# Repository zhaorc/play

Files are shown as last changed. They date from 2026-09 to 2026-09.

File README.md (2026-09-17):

# 纸带钢琴工坊

将 MIDI 乐曲转换为机械纸带钢琴的打孔数据，提供从编曲、试听到上机打孔的一体化工具链。

目标机器是一台机械纸带钢琴：双排键盘（上排和弦、下排主旋律）每档 8 个白键（简化键盘槽位 15 格、每排 17 条滚轮轨），纸带自下而上走带，孔位经过滚轮触发拨片发声。换挡键孔（◀◀/▶▶）可移动键盘音域窗口（每按一次 ±1 档 = 一个八度），8 个档位 A0→A1→A2→A3→A4→A5→A6→C7 合起来覆盖钢琴全音域 A0..C8。

## 仓库结构

```
play/
├── perfect-piano/            纸带打孔工作室（网页应用，零依赖）
│   ├── index.html            主程序入口（双击即用）
│   ├── test.html             自测页（137 项断言）
│   ├── js/
│   │   ├── pp-tape.js        纸带数据模型与 MIDI 转换管线（核心）
│   │   ├── app.js            主程序：渲染 / 编辑 / 播放 / 导出
│   │   ├── midi-parser.js    MIDI 文件解析
│   │   ├── synth.js          Web Audio 发声模拟
│   │   └── punch-sender.js    打孔机上位机（Web Serial）
│   ├── test/                 换挡逻辑测试曲（MIDI）
│   └── tools/                测试曲生成脚本
├── puncher/
│   └── firmware/puncher/     Arduino Nano 打孔机固件（puncher.ino）
├── midi/                     示例曲（梦中的婚礼、土耳其进行曲）
├── 打孔机.md                 打孔机硬件规格
└── 打孔机-设计方案.md         打孔机设计文档（架构 / 标定 / 协议）
```

## 快速开始

1. **打开工作室**：双击 `perfect-piano/index.html`（推荐 Chrome / Edge，零安装零依赖）。
2. **导入乐曲**：点击「导入 MIDI」选择 `.mid` 文件，或使用「示例曲」直接体验。
   - 多轨文件默认按音域均值自动分配：最高轨 → 主旋律（下排），其余轨 → 和弦（上排）。
   - 单轨文件默认开启「按音高拆分」，低于 C4 的音自动归入和弦排。
3. **预览试听**：播放模拟真实纸带机行为（含换挡时序、双排 105mm 站间错位）。
4. **导出图纸**：导出 1:1 SVG / PNG 用于参考，或保存工程 JSON 后续编辑。

## MIDI 转换管线

- 音高按原音精确落轨（不做移调）：白键/黑键各占自己的槽位，虚拟黑键位（B-C、E-F 处）占位不发声
- 超出当前档位窗口时自动调度换挡键孔：基于真实时间提前量（400ms 换挡 + 200ms 余量）
- 密集音符物理无法打孔时（同轨孔心距 < 4.0mm）自动整曲拉长每拍毫米数，节奏零失真
- 同拍双排孔在带长方向相距 105mm（两排滚轮的物理站间距）

## 打孔机

网页端「打孔机」面板通过 Web Serial（115200）控制 Arduino Nano 固件，完成自动打孔：

- **固件**：`puncher/firmware/puncher/puncher.ino`（Arduino Nano + 2×THB6128 + PWM 舵机）
  - X 轴：Φ24mm 滚轮走带（339.53 脉冲/mm）；Y 轴：1模21齿齿轮齿条（388.03 脉冲/mm）
  - 梯形加减速脉冲引擎、打孔状态机（下压 45° → 钻孔 2s → 抬起 90°）
  - ASCII 行协议：`V/O/J/P/Z0/Z1/F/C/Q/R`；EEPROM 保存标定当量；急停与预留限位
- **上位机**：工作室内打孔面板——点动对刀、设原点、当量校准、逐孔 ACK 流控、暂停/急停、`.punch` 任务文件导出

使用流程：连接 → 点动对刀 → 设为原点 → 生成任务 → 开始打孔。

详细设计见 [打孔机-设计方案.md](打孔机-设计方案.md)。

## 自测

浏览器打开 `perfect-piano/test.html`，覆盖槽位模型、档位表、轨位几何、换挡调度、最密间隔拉长、端到端转换、打孔任务生成等 174 项断言。

## 硬件规格摘要

| 项 | 值 |
|---|---|
| 纸带宽 | 150mm |
| 档位宽 | 130mm（N=8 白键，白:黑 = 7:6） |
| 每排轨数 | 17（◀◀ + 15 槽位 + ▶▶），槽栅距 8.622mm，上下排错开 D=4.311mm |
| 每拍走带 | 9mm（默认，密集曲自动拉长） |
| 两排站间距 | 105mm（沿走带方向） |
| 换挡 | 整档键 ±1 挡（= 一个八度），耗时 400ms，提前量 600ms，曲首连按 3 次 ◀◀ 钉底 A0 |
| 最小孔距 | 4.0mm（任意两孔孔心距 ⟺ 孔缘间距 1.5mm） |

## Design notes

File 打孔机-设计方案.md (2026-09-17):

# 打孔机程序设计方案

> 依据：`打孔机.md` 硬件规格（2026-09-14）
> 状态：**已确认，固件 v1.0 已完成**（Nano 编译通过：Flash 29% / RAM 17%；确认结论见第六节）

## 一、系统总体架构

```
┌─────────────────────────┐   USB 串口(有线)   ┌──────────────────────┐
│  PC 端（上位机）          │  文本行协议 115200  │  Arduino Nano 固件     │
│  perfect-piano 网页扩展  │ ◄──────────────► │  ATMEGA328P (2KB RAM) │
│  · 孔位→机器坐标换算      │   P / J / O / R   │  · X/Y 步进脉冲发生    │
│  · 手动对刀/校准/试打      │                   │  · Z 伺服打孔循环      │
│  · 任务流式下发+进度回读   │                   │  · 逐孔 ACK 流控       │
└─────────────────────────┘                   └──────────────────────┘
                                                      │
                              X: THB6128→17HS2408s（滚轮走带）
                              Y: THB6128→17HS2408s（齿轮齿条横移）
                              Z: 舵机/伺服 45°下 / 90°抬
```

数据流复用现有成果：`state.holes`（col,row,lane）→ `PP.holeYMM()` 和 `PP.laneXMM()` → 毫米坐标 → 串口逐孔下发，固件负责脉冲与打孔时序。

## 二、机械标定（关键常量）

128 细分下每圈脉冲 = 200 × 128 = **25600 脉冲/圈**

| 轴 | 传动 | 每圈走距 | 理论脉冲/mm |
|---|---|---|---|
| X（走带长度方向） | Φ24mm 滚轮直连摩擦 | π×24 = 75.40mm | **339.53** |
| Y（纸带宽度方向） | 1模21齿齿轮齿条，节圆 Φ21mm | π×21 = 65.97mm | **388.03** |
| Z | 伺服 | 90°抬 / 45°下，下压保持 **2s** | — |

- 理论值仅作初值，固件支持标定命令微调（补偿滚轮打滑/齿轮公差），存入 EEPROM
- 坐标映射：**机器 X = 纸带长度（holeYMM），机器 Y = 纸带宽度（laneXMM，约 3.44~146.56mm）**
- 行程上限：Y 需覆盖 150mm 带宽（≈5820 脉冲）；X 一首歌可达数米，脉冲数用 int32（上限约 6km，安全）
- 孔按 **机器 x（纸带长度）升序为主、y（宽度）升序为辅** 排列打孔顺序——纸带单向进给不可倒带，同 x 位置的孔先打低 y 再打高 y

## 三、固件设计（`puncher/firmware/puncher/puncher.ino`，已实现并编译通过）

**引脚分配**

| 信号 | 引脚 | 说明 |
|---|---|---|
| X: PUL/DIR/ENA | D2/D3/D4 | THB6128 光耦输入，ENA 低有效 |
| Y: PUL/DIR/ENA | D5/D6/D7 | THB6128 光耦输入，ENA 低有效 |
| X 原点限位（预留） | D8 | INPUT_PULLUP，未装时空置；移动中触发即急停 |
| Z 舵机 | D9 | PWM 50Hz，Servo 库（ATmega328P 硬件 PWM 引脚） |
| 硬件急停按钮（预留） | A0 | INPUT_PULLUP，未接空置；轮询触发等同 `R` 命令 |
| Y 原点限位（预留） | A1 | INPUT_PULLUP，未装时空置 |

**实现要点**

- 脉冲用 `digitalWrite` + `micros()` 定时（10mm/s 进给 ≈ 3.4~3.9kHz，Nano 无压力）；非阻塞状态机，每步按加减速斜坡实时算脉冲间隔，保证 `R` 急停随时可响应
- 单孔动作序列：X 进给到位 → Y 横移到位 → Z 舵机转到 45° → 保持 2.0s → Z 回到 90° → 回 `DONE`
- RAM 只保留单行命令缓冲（2KB 内存限制），靠上位机 ACK 流控（收到 DONE 再发下一孔），不做整块缓存；执行中收到除 `R` 外命令回 `ERR BUSY`
- 上电默认 Z=90°（抬起）、使能步进、等待原点设定；EEPROM 存 magic+脉冲当量，首次烧录自动写默认值
- Z 轴确认为标准 PWM 舵机（3 线，50Hz，脉宽 0.5~2.5ms 对应 0~180°），由 D9 硬件 PWM 输出；舵机须独立供电（5V BEC），勿取 Nano USB 电源

**串口协议**（ASCII 行，`\n` 结尾，应答 `OK/DONE/ERR`）

| 命令 | 含义 |
|---|---|
| `V` | 版本握手，回 `PUNCHER v1.0 READY` |
| `O` | 当前位置设为原点（手动对刀后） |
| `J <x> <y>` | 点动到绝对毫米位置（不打孔），到位回 DONE |
| `P <x> <y>` | 在绝对坐标打一个孔（走完+2s循环，回 DONE） |
| `Z0 / Z1` | 手动抬钻 90° / 压钻 45°（调试用） |
| `F <mm/s>` | 设置进给速度（默认 10，范围 1~50） |
| `C <xpmm> <ypmm>` | 校准脉冲当量，写 EEPROM 永久保存 |
| `Q` | 查询当前位置，回 `POS <xmm> <ymm>` |
| `R` | 急停：立即停脉冲、抬钻，回 `OK ESTOP` |

## 四、PC 端设计（扩展现有网页）

新增 `js/punch-sender.js` + 界面"打孔"面板：

1. **任务生成**：从当前 `state.holes` 直接换算毫米坐标（含换挡键孔，lane 0/16 在档位宽度外 shiftGap=4.4mm 处），按走带方向排序；可导出 `.punch` 文本任务文件（每行 `P x y`）离线备用
2. **连接与控制**：Web Serial API（Chrome/Edge），连接/断开、115200、版本握手
3. **对刀流程**：手动点动 X/Y → 钻头对准纸带头部第一孔位参考点 → `O` 设原点
4. **执行面板**：试打单孔（不装钻头干跑 Z）→ 试打前 N 孔 → 整曲发送；实时进度（第 k/总孔数、当前坐标），暂停/继续/急停
5. **校准面板**：输入实测走距反推脉冲当量，下发 `C`
6. 安全细节：发送前显示"X 总行程 xx 米 / 共 xx 孔 / 预计 xx 分钟"（每孔 2s+进给时间）需确认；Z 抬起状态失能"开始"

## 五、实施步骤

1. ✅ `puncher/firmware/puncher/puncher.ino` 固件 + 协议解析/脉冲引擎/打孔状态机（2026-09-14 完成，arduino-cli 编译通过）
2. ✅ `test.html` 协议层纯逻辑断言：任务排序（x 主序 y 次序）、坐标映射、拉长曲换算、P 命令格式、用时估算、.punch 导出（2026-09-14 完成，含 14 项"打孔："断言）
3. ✅ 网页端打孔面板 + Web Serial + 任务生成/导出（`js/punch-sender.js`，2026-09-14 完成：连接/握手/对刀/点动/进给/校准/试打/逐孔 ACK 流控/暂停/急停/.punch 导出）
4. 无硬件自测：固件协议用 PC 端串口模拟器对跑（干跑模式，禁 Z）
5. 上机调试：对刀→单孔→多孔→整曲

## 六、确认结论（2026-09-14）

1. **轴向对应**：✅ 机器 X（滚轮走带）= 纸带**长度方向**；机器 Y（齿轮齿条）= 纸带**宽度方向**。固件映射：机器 (x, y) = (holeYMM, laneXMM)
2. **原点方案**：✅ 默认"手动对刀 + `O` 软件设原点"；固件同时预留 X(D8)/Y(A1) 限位引脚与 A0 硬件急停，未安装时空置不影响使用，后期装开关即可扩展自动回零
3. **上位机形态**：✅ 集成进现有 perfect-piano 网页，Web Serial API（Chrome/Edge 桌面；Android Chrome + OTG 亦可），实际使用走 localhost 或 https 安全上下文
4. **Z 轴接口**：✅ 确认为 **PWM 舵机**（50Hz，45° 下压 / 90° 抬起，下压保持 2s），接 D9 硬件 PWM，Servo 库驱动，独立 5V 供电

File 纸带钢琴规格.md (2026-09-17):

* 1、纸带钢琴.png是手机上的钢琴app的截图，键盘模式，双排键盘，标准键盘（既有白健也有黑键），每个档位是N个白键，N是可调节参数。
* 2、初始档位是A0档，记住：xx档的意思是最左侧是xx键的档位。
* 3、最低档是A0，最高档是C7档（机械上止点；C7 档窗口 C7..C8，与各低档合起来覆盖钢琴全音域 A0..C8）
* 3.1、N 取值定为 8（唯一自洽解：窗口 2N-1=15 槽 = 13 真实键 + 2 虚拟黑键位，档位步进 14 槽恰为一个八度）
* 4、单箭头按钮未使用，两侧双箭头按钮点击后切换档位，按一次切换一个档位（单换挡，即整档键 ±1 档 = ±12 半音），换档时间约400毫秒，到位前键盘仍按旧档击发
* 5、上排弹奏和旋，下排弹奏主旋律
* 6、每个按键（白健、黑键）、双箭头按钮由一个滚轮带动拨片控制，滚轮由打孔纸带驱动（类似纸带音乐盒）
* 7、共有两排滚轮分别控制两排键盘，控制和旋的称为上排滚轮，控制主旋律的称为下排滚轮
* 8、两排滚轮平行排列、在纸带的运动方向上的间距是105mm，为防止干涉，下排滚轮比上排滚轮向右偏移D毫米，D由计算得出。
* 9、纸带总宽度是150mm。档位宽度（最左键的左侧到最右键的右侧的距离）是130mm。
* 9.1、由档位宽度 130mm 与 N=8（白:黑 = 7:6）定出：白键宽 w=130×7/98≈9.286mm，黑键宽 b=6w/7≈7.959mm，槽栅距（相邻槽位中心距）p=(w+b)/2=13w/14≈8.622mm
* 9.2、D 取半槽栅距 p/2≈4.311mm：两排在统一槽栅上错开半个槽位，跨排任意两孔孔心距最小恰为 D≈4.311mm
* 10、换挡控制滚轮不占用档位宽度，档位宽度全部用来排布键盘控制滚轮。
* 11、标准键盘的黑键是嵌在相邻的两个白健之间，黑键的长度约为白健的一半。将键盘布局简化一下，简化后的键盘，黑键和白健的长度相同，每两个白健之间都有一个黑键（对于实际不存在的黑键，比如EF之间没有黑键也要插入一个虚拟黑键用来占位），白健与黑键宽度比值是7:6
* 12、纸带的打孔直径为2.5mm（孔半径1.25mm），要求孔间距不能小于1.5mm（指孔边缘之间的距离，即任意两孔孔心距不小于 1.5+2.5=4.0mm），最外侧孔缘距纸带边界不小于1.5mm。
* 12.1、换挡滚轮中心距档位边缘 shiftGap=4.4mm（两侧对称）；该布局下最外孔缘距带边约2.19mm，跨排孔心距最小为 D≈4.311mm、换挡孔与对排端键孔约4.732mm，均满足规格，无需事后微移。

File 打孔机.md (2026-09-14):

# 打孔机
* 打孔机的x轴是由步进电机（记作电机x）直连滚轮通过摩擦力带动纸带沿x轴方向行走，滚轮直径24mm
* 打孔机的y轴是由步进电机（记作电机y）通过齿轮带动齿条沿y轴行走，齿轮规格是1模21齿
* 打孔机的z轴是由PWM舵机（记作电机z）带动打孔钻头沿z轴引动，钻头抬起的伺服电机行程角度是90度，钻头放下的电机角度是45度，钻孔时间为2s
* 打孔机的控制板是Arduino Nano（ATMEGA328P）
* 步进电机型号是NEMA 17HS2408s，驱动板是THB6128，采用128细分
* 电脑作为打孔数据输入端，有线连接

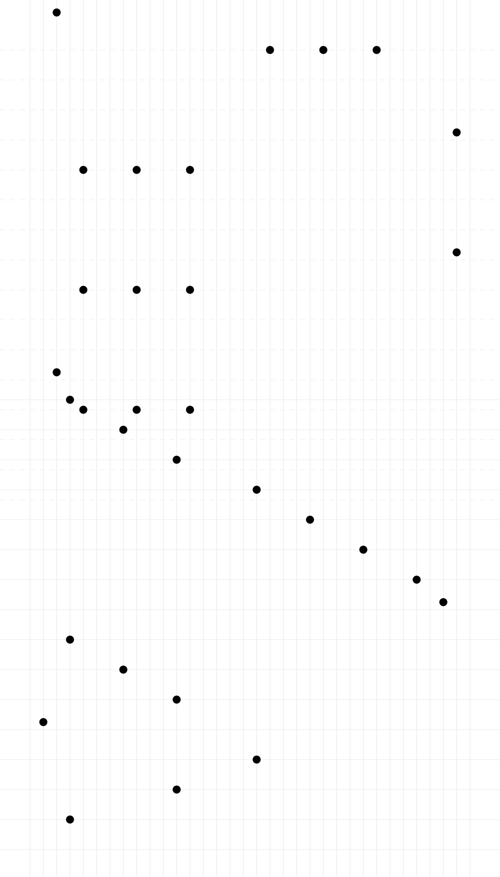
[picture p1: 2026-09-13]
纸带打孔图.png

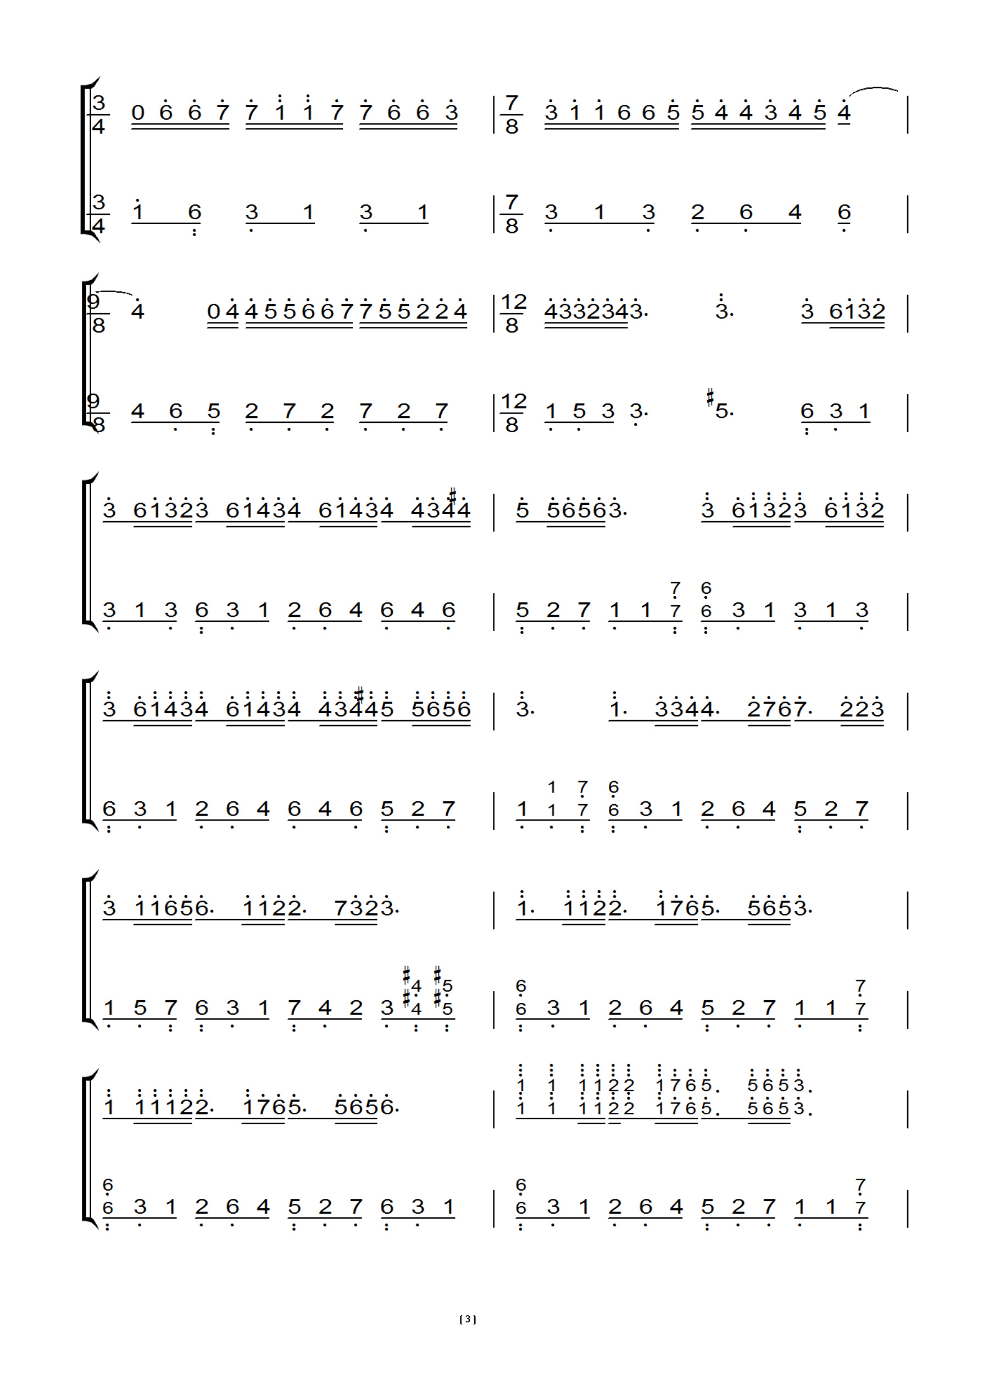
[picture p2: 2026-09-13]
梦中的婚礼.png

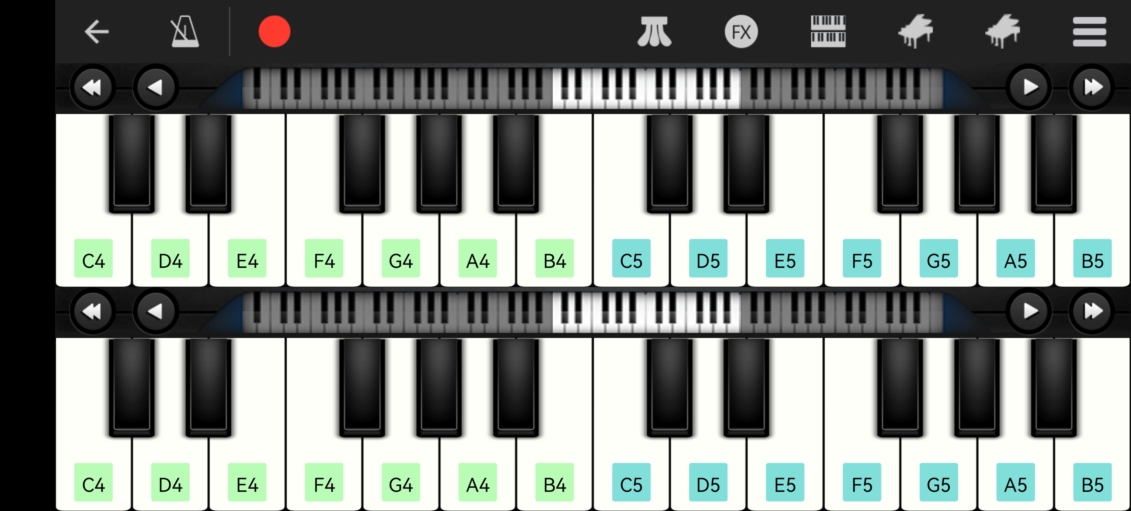
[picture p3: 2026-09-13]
纸带钢琴.jpg

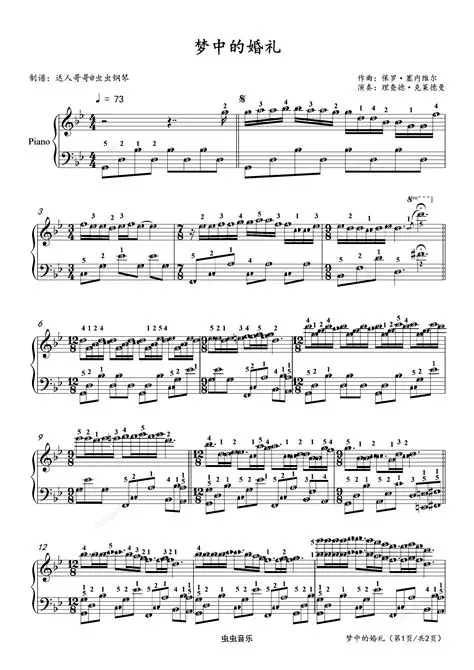
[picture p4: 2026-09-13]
梦中的婚礼.webp

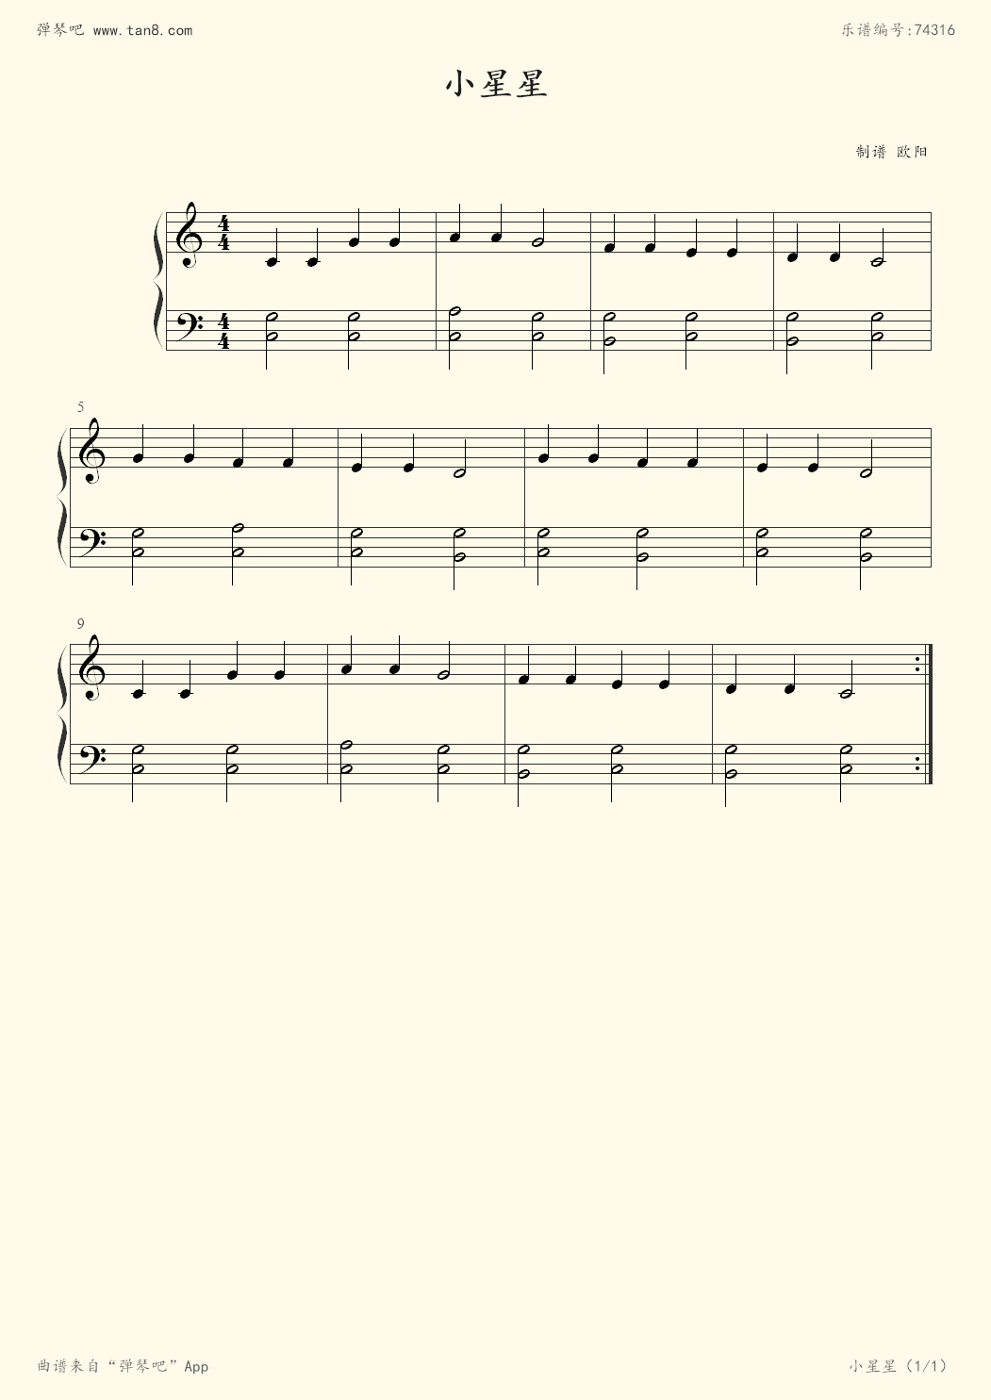
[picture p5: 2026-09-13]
小星星.png

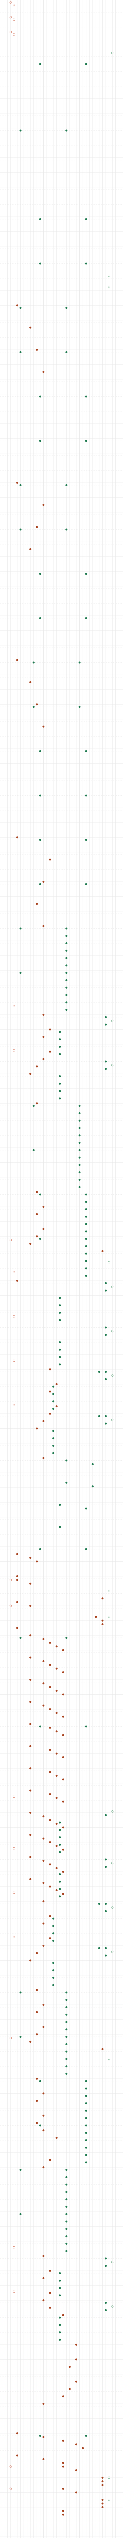
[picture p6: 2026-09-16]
perfect-piano/westworld_theme_纸带.png

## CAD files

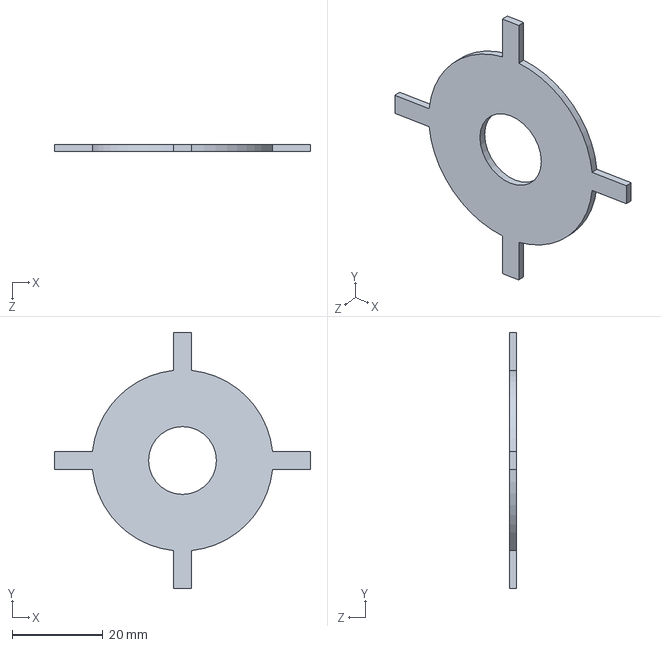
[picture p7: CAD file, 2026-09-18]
cad/roller_d40x1p5_h15.SLDPRT
56.6 x 56.6 x 1.50 mm

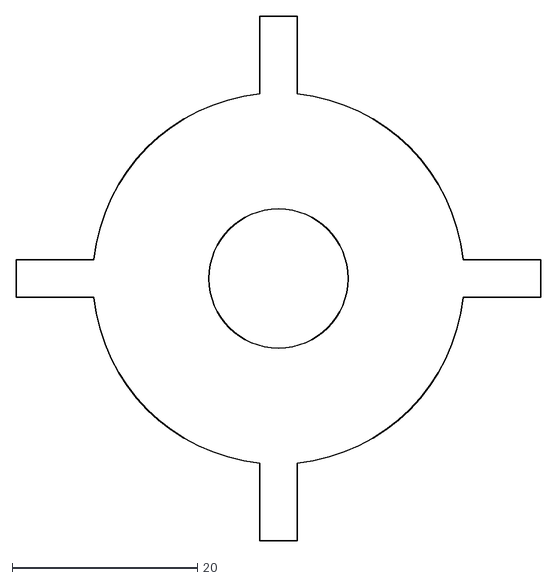
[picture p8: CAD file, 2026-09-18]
cad/roller_laser_pvc1p5.dxf
56.6 x 56.6

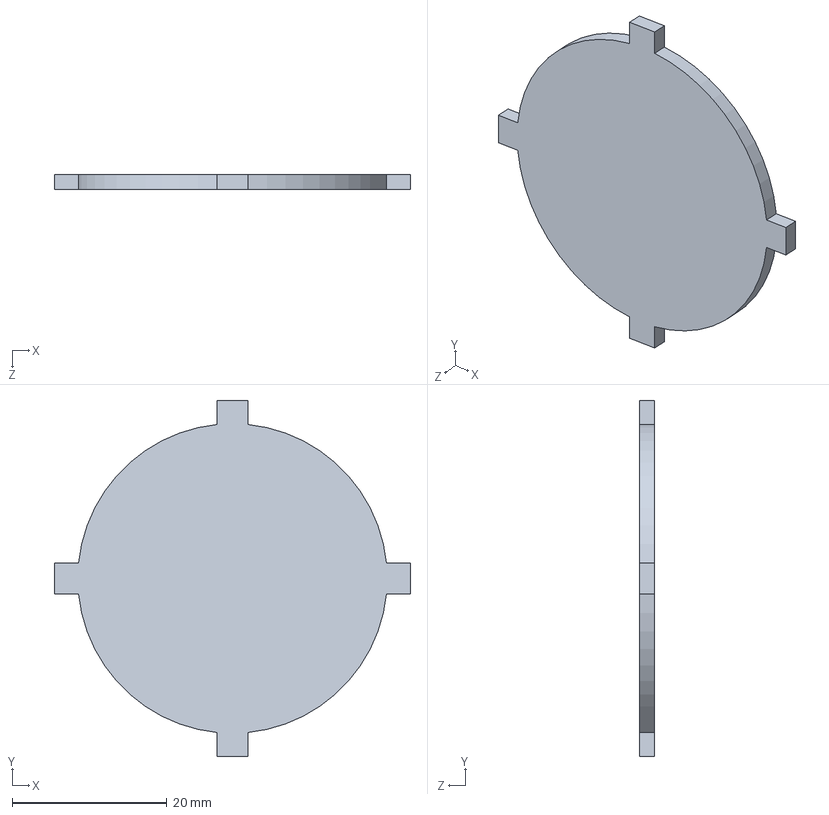
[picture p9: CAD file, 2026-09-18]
cad/roller_d40x2_4bumps.SLDPRT
46.0 x 46.0 x 2.00 mm

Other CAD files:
cad/roller_d40x1p5_h15_views.SLDDRW
cad/roller_d40x2_4bumps_views.SLDDRW

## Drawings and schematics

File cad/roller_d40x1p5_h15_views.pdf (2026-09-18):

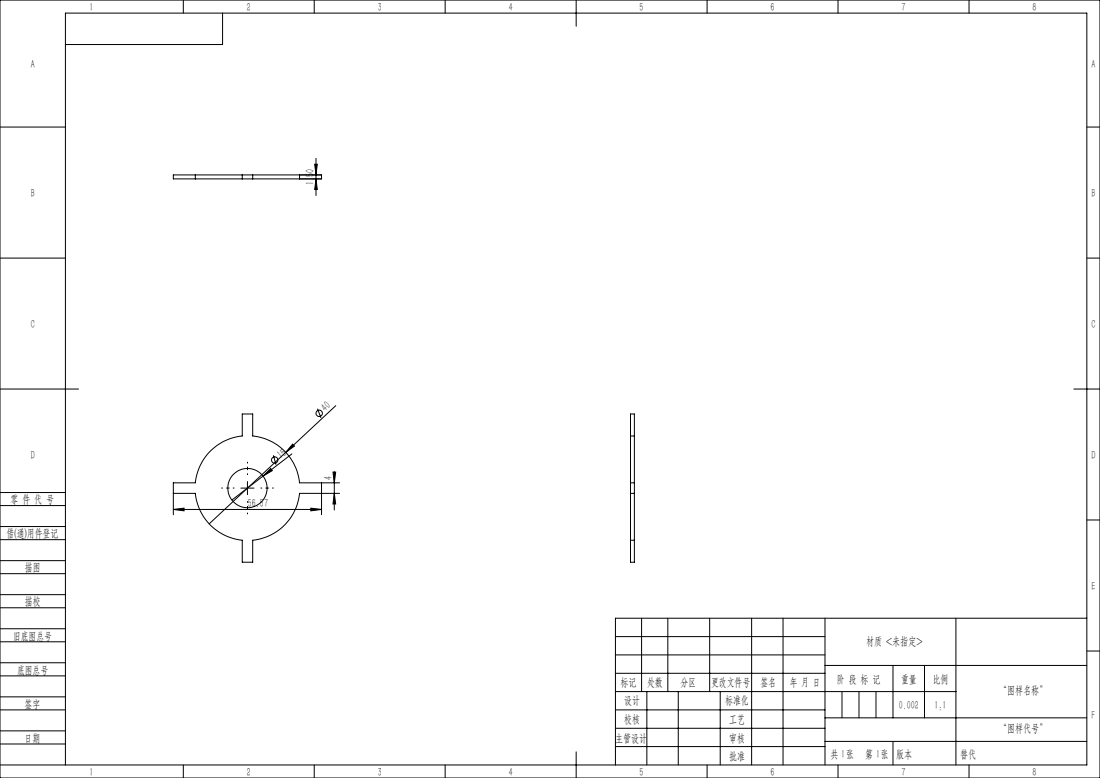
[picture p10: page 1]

材质 <未指定>

阶 段 标 记 | 重量 | 比例 | “图样名称”

标记 | 处数 | 分区 | 更改文件号 | 签名 | 年 月 日
设计 | | | 标准化 | | | | | 0.002 | 1:1
校核 | | | 工艺
主管设计 | | | 审核

“图样代号”

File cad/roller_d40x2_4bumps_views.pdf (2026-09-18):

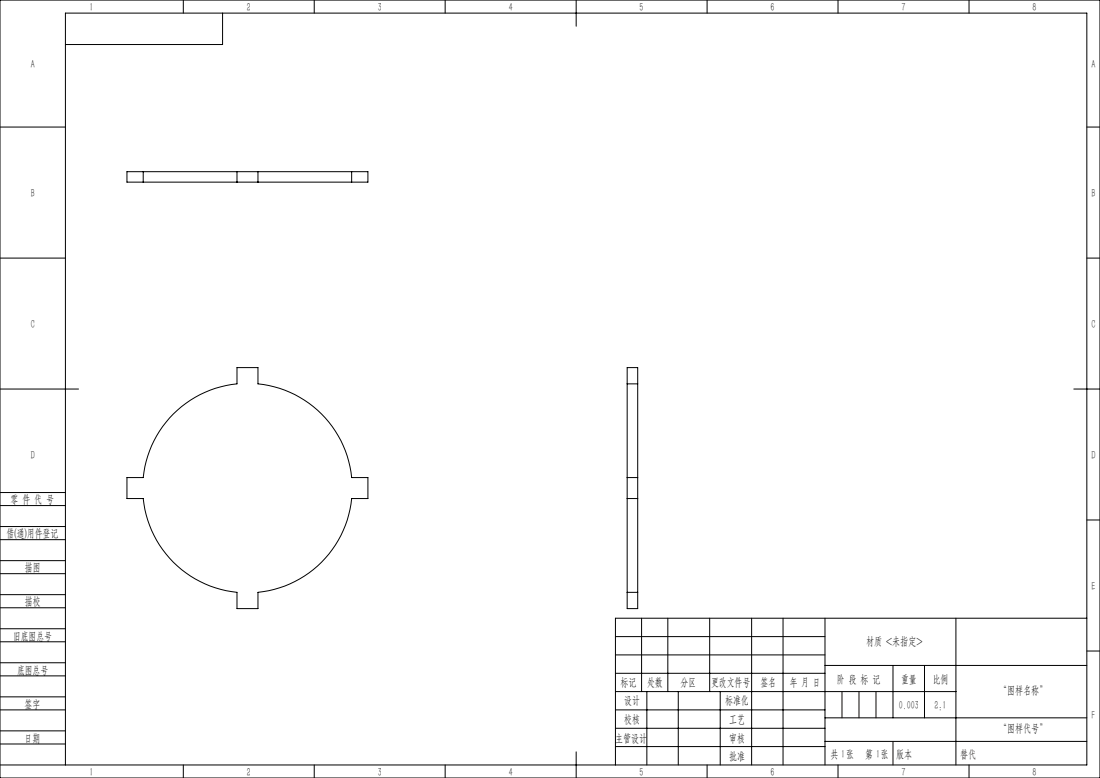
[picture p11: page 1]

材质 <未指定>

阶 段 标 记 | 重量 | 比例 | “图样名称”

标记 | 处数 | 分区 | 更改文件号 | 签名 | 年 月 日
设计 | | | 标准化 | | | | | 0.003 | 2:1
校核 | | | 工艺
主管设计 | | | 审核

“图样代号”

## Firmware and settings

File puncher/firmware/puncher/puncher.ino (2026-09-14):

/* ============================================================
 * 打孔机固件 puncher.ino
 * 纸带钢琴打孔机 · Arduino Nano (ATmega328P)
 *
 * 硬件（依据 打孔机.md / 打孔机-设计方案.md）：
 *   X 轴：NEMA 17HS2408 + THB6128（128 细分），直连 Φ24mm 滚轮摩擦走带
 *         25600 脉冲/圈 → π×24 = 75.40mm/圈 → 339.53 脉冲/mm
 *   Y 轴：同款电机驱动，1模21齿齿轮 + 齿条，节圆 Φ21mm
 *         25600 脉冲/圈 → π×21 = 65.97mm/圈 → 388.03 脉冲/mm
 *   Z 轴：PWM 舵机（50Hz，独立 5V 供电），90° 抬起 / 45° 下压，钻孔 2s
 *   通信：USB 串口 115200，ASCII 行协议（\n 结尾）
 *
 * 坐标约定：机器 X = 纸带长度方向（走带），机器 Y = 纸带宽度方向
 *           固件映射：机器 (x, y) = (holeYMM, laneXMM)
 *
 * 接线（D2..D7 全在 PORTD，脉冲用端口直写保证速度）：
 *   X: PUL=D2  DIR=D3  ENA=D4（低有效=使能）
 *   Y: PUL=D5  DIR=D6  ENA=D7（低有效=使能）
 *   Z 舵机信号 = D9（舵机电源必须外接 5V，勿用 Nano USB 供电）
 *   预留：X 限位=D8  Y 限位=A1  硬件急停按钮=A0（均 INPUT_PULLUP，
 *         常开接地触发；不安装时悬空不影响使用）
 *
 * 串口协议（应答 OK / DONE / ERR <原因>，DONE 表示单孔/点动完成）：
 *   V                版本握手，回 "PUNCHER v1.0 READY"
 *   O                当前位置设为原点（手动对刀后）；急停后须先 O 才能恢复运动
 *   J <x> <y>        点动到绝对毫米坐标（不打孔），到位回 DONE
 *   P <x> <y>        在绝对坐标打一个孔（X→Y→下钻2s→抬钻），回 DONE
 *   Z0 / Z1          手动抬钻(90°) / 压钻(45°)，调试用
 *   F <mm/s>         进给速度 1~50（默认 10，掉电不保存）
 *   C <xpmm> <ypmm>  校准脉冲当量，写 EEPROM 永久保存
 *   Q                查询位置，回 "POS <xmm> <ymm>"
 *   R                急停：立即停脉冲、抬钻，回 "OK ESTOP"
 * ============================================================ */

#include <Servo.h>
#include <EEPROM.h>

// ---------------- 固件版本 ----------------
#define FW_NAME    "PUNCHER"
#define FW_VER     "v1.0"

// ---------------- 引脚 ----------------
#define X_PUL      2   // PD2
#define X_DIR      3   // PD3
#define X_ENA      4   // PD4
#define Y_PUL      5   // PD5
#define Y_DIR      6   // PD6
#define Y_ENA      7   // PD7
#define X_LIM      8   // 预留：X 限位/原点开关
#define Z_SERVO    9   // 舵机信号（硬件 PWM）
#define ESTOP_BTN  A0  // 预留：硬件急停按钮
#define Y_LIM      A1  // 预留：Y 限位/原点开关

// ---------------- 机械常量 ----------------
#define STEPS_PER_REV   200
#define MICROSTEPS      128
#define PULSES_PER_REV  ((int32_t)STEPS_PER_REV * MICROSTEPS)   // 25600
#define X_ROLLER_DIA_MM 24.0f     // X 滚轮直径
#define Y_PITCH_DIA_MM  21.0f     // Y 齿轮节圆直径（1模×21齿）
// 理论脉冲当量：X = 25600/(π×24) = 339.53 /mm；Y = 25600/(π×21) = 388.03 /mm
#define X_PMM_DEFAULT   (PULSES_PER_REV / (3.14159265f * X_ROLLER_DIA_MM))
#define Y_PMM_DEFAULT   (PULSES_PER_REV / (3.14159265f * Y_PITCH_DIA_MM))

// ---------------- 舵机 / 钻孔时序 ----------------
#define SERVO_UP_DEG     90      // 抬起
#define SERVO_DOWN_DEG   45      // 下压
#define SERVO_TRAVEL_MS  500     // 舵机到位等待（含余量）
#define DRILL_MS         2000    // 钻孔保持时间（规格：2s）

// ---------------- 运动参数 ----------------
#define FEED_DEFAULT     10.0f    // 默认进给 mm/s
#define FEED_MIN         1.0f
#define FEED_MAX         50.0f    // 上限：主循环四项巡检约 40µs，>40mm/s 时脉冲节拍可能轻微滞后
#define PUL_HIGH_US      10      // 脉冲高电平宽度 µs
#define RAMP_PULSES      200     // 加减速斜坡脉冲数（约 0.6mm）
#define MIN_CRUISE_US    30      // 最短脉冲周期保护
#define MAX_INT_US       60000   // uint16 上限保护

// ---------------- EEPROM 布局 ----------------
#define EE_MAGIC         0xA5
#define EE_ADDR_MAGIC    0
#define EE_ADDR_XPMM     1        // float
#define EE_ADDR_YPMM     5        // float
#define PMM_MIN          50.0f    // 校准值合法范围
#define PMM_MAX          5000.0f

// ---------------- 串口行缓冲 ----------------
#define LINE_BUF         32

// ============================================================
// 运动引擎（非阻塞，micros() 定时，梯形加减速）
// ============================================================
struct Axis {
  uint8_t  pulMask;     // PORTD 位掩码
  uint8_t  dirMask;
  int32_t  pos;         // 绝对位置（脉冲，原点=0）
  bool     moving;
  bool     pulseHigh;   // 当前脉冲电平
  bool     dirPos;      // true = 正方向
  int32_t  total;       // 本次移动总脉冲数
  int32_t  done;        // 已完成脉冲数
  int32_t  rampLen;     // 实际斜坡长度（短行程自动折半）
  uint16_t cruiseInt;   // 巡航周期 µs
  uint16_t startInt;    // 起步周期 µs（= 巡航×4）
  uint32_t nextT;       // 下一脉冲边沿时刻 µs
};

static Axis ax, ay;                 // X 走带 / Y 横移
static float xpmm, ypmm;            // 脉冲/mm（EEPROM 校准值）
static float feedMmS = FEED_DEFAULT;

// ============================================================
// 打孔状态机
// ============================================================
enum State { ST_IDLE, ST_MOVE_X, ST_MOVE_Y,
             ST_DRILL_DOWN, ST_DRILL_DWELL, ST_DRILL_UP };
static State  st = ST_IDLE;
static bool   drilling = false;     // P 命令 = true（J 命令跳过钻孔）
static bool   estopped = false;    // 急停标志，须 O 清除
static float  targetXmm, targetYmm;
static uint32_t phaseT;            // 钻孔各阶段起始时刻

static Servo zServo;

// ---------------- 应答助手（F() 宏省 RAM） ----------------
static void replyOk()   { Serial.println(F("OK")); }
static void replyDone() { Serial.println(F("DONE")); }
static void replyErr(const __FlashStringHelper *m) {
  Serial.print(F("ERR ")); Serial.println(m);
}

// ---------------- EEPROM 配置 ----------------
static void saveConfig() {
  EEPROM.update(EE_ADDR_MAGIC, EE_MAGIC);
  EEPROM.put(EE_ADDR_XPMM, xpmm);
  EEPROM.put(EE_ADDR_YPMM, ypmm);
}
static void loadConfig() {
  bool valid = (EEPROM.read(EE_ADDR_MAGIC) == EE_MAGIC);
  if (valid) {
    EEPROM.get(EE_ADDR_XPMM, xpmm);
    EEPROM.get(EE_ADDR_YPMM, ypmm);
  }
  // 用 !(x>=min && x<=max) 形式：EEPROM 损坏读出 NaN 时也会被判无效
  if (!valid || !(xpmm >= PMM_MIN && xpmm <= PMM_MAX) ||
                !(ypmm >= PMM_MIN && ypmm <= PMM_MAX)) {
    xpmm = X_PMM_DEFAULT;
    ypmm = Y_PMM_DEFAULT;
    saveConfig();
  }
}

// ---------------- 运动引擎 ----------------
// 梯形速度：起步周期 = 巡航×4，RAMP_PULSES 内线性逼近巡航；
// 短行程（< 2×RAMP）自动退化为三角形速度曲线
static uint16_t moveInterval(const Axis &a) {
  int32_t i = a.done;
  int32_t r = (i < a.total - i) ? i : (a.total - i);   // min(i, total-i)
  if (r >= a.rampLen) return a.cruiseInt;
  // r ∈ [0, rampLen)：startInt → cruiseInt 线性插值
  uint32_t span = (uint32_t)(a.startInt - a.cruiseInt);
  uint32_t iv = a.cruiseInt + span * (uint32_t)(a.rampLen - r) / (uint32_t)a.rampLen;
  return (uint16_t)iv;
}

// 发起一次绝对移动（毫米）；零距离立即完成
static void beginMove(Axis &a, float mm, float pmm) {
  int32_t target = (int32_t)(mm * pmm + (mm >= 0 ? 0.5f : -0.5f));
  int32_t delta = target - a.pos;
  a.total = (delta < 0) ? -delta : delta;
  a.done = 0;
  a.pulseHigh = false;
  if (a.total == 0) { a.moving = false; return; }
  a.dirPos = (delta > 0);
  if (a.dirPos) PORTD |= a.dirMask; else PORTD &= ~a.dirMask;

  a.rampLen = RAMP_PULSES;
  if (a.rampLen > a.total / 2) a.rampLen = a.total / 2;

  uint32_t cruise = (uint32_t)(1000000.0f / (feedMmS * pmm));
  if (cruise < MIN_CRUISE_US) cruise = MIN_CRUISE_US;
  if (cruise > MAX_INT_US)    cruise = MAX_INT_US;
  uint32_t startI = cruise * 4;
  if (startI > MAX_INT_US)    startI = MAX_INT_US;
  a.cruiseInt = (uint16_t)cruise;
  a.startInt  = (uint16_t)startI;

  a.moving = true;
  a.nextT  = micros() + 500;   // 换向/方向建立延时
}

// 每圈调用：按当前斜坡周期发射脉冲（不阻塞）
static void axisTick(Axis &a) {
  if (!a.moving) return;
  uint32_t now = micros();
  if ((int32_t)(now - a.nextT) < 0) return;
  if (!a.pulseHigh) {
    PORTD |= a.pulMask;            // 上升沿
    a.pulseHigh = true;
    a.nextT = now + PUL_HIGH_US;
  } else {
    PORTD &= ~a.pulMask;           // 下降沿，一个完整脉冲结束
    a.pulseHigh = false;
    a.pos += a.dirPos ? 1 : -1;
    a.done++;
    if (a.done >= a.total) { a.moving = false; return; }
    a.nextT = now + moveInterval(a) - PUL_HIGH_US;
  }
}

// ---------------- 急停 ----------------
static void estopAll() {
  ax.moving = false;
  ay.moving = false;
  PORTD &= ~(ax.pulMask | ay.pulMask);   // 强制脉冲线拉低
  zServo.write(SERVO_UP_DEG);            // 抬钻
  st = ST_IDLE;
  estopped = true;
  Serial.println(F("OK ESTOP"));
}

// ---------------- 状态机推进 ----------------
static void finishTask() {
  st = ST_IDLE;
  replyDone();
}

static void runMachine() {
  switch (st) {
    case ST_MOVE_X:
      axisTick(ax);
      if (!ax.moving) { beginMove(ay, targetYmm, ypmm); st = ST_MOVE_Y; }
      break;
    case ST_MOVE_Y:
      axisTick(ay);
      if (!ay.moving) {
        if (drilling) {
          zServo.write(SERVO_DOWN_DEG);
          phaseT = millis();
          st = ST_DRILL_DOWN;
        } else {
          finishTask();               // J 命令到位
        }
      }
      break;
    case ST_DRILL_DOWN:                // 等舵机下压到位
      if (millis() - phaseT >= SERVO_TRAVEL_MS) { phaseT = millis(); st = ST_DRILL_DWELL; }
      break;
    case ST_DRILL_DWELL:               // 钻孔保持 2s
      if (millis() - phaseT >= DRILL_MS) {
        zServo.write(SERVO_UP_DEG);
        phaseT = millis();
        st = ST_DRILL_UP;
      }
      break;
    case ST_DRILL_UP:                  // 等舵机抬起到位
      if (millis() - phaseT >= SERVO_TRAVEL_MS) finishTask();
      break;
    default:
      break;
  }
}

// ---------------- 限位 / 急停按钮 ----------------
static void checkLimits() {
  // 预留限位：运动中触发（常开接地）即急停；未安装时上拉恒高无影响
  if ((ax.moving && digitalRead(X_LIM) == LOW) ||
      (ay.moving && digitalRead(Y_LIM) == LOW)) {
    estopAll();
  }
}

static void checkEstopBtn() {
  // 预留硬件急停：低电平持续 30ms 触发（时间去抖）
  static uint8_t  phase = 0;
  static uint32_t t0 = 0;
  bool low = (digitalRead(ESTOP_BTN) == LOW);
  if (phase == 0) {
    if (low) { phase = 1; t0 = millis(); }
  } else if (phase == 1) {
    if (!low) phase = 0;
    else if (millis() - t0 >= 30) {
      phase = 2;
      if (!estopped) estopAll();
    }
  } else {
    if (!low) phase = 0;
  }
}

// ---------------- 串口命令处理 ----------------
static bool parse2f(char *s, float &a, float &b) {
  char *e1, *e2;
  a = strtod(s, &e1);
  if (e1 == s) return false;
  b = strtod(e1, &e2);
  return (e2 != e1);
}

static void handleLine(char *buf) {
  // 去尾部空白
  size_t n = strlen(buf);
  while (n && (buf[n-1] == ' ' || buf[n-1] == '\t' || buf[n-1] == '\r')) buf[--n] = 0;
  if (n == 0) return;

  char c = buf[0];
  if (c >= 'a' && c <= 'z') c -= 32;    // 大小写不敏感
  bool idle = (st == ST_IDLE);

  switch (c) {
    case 'V':
      Serial.print(F(FW_NAME " " FW_VER " "));
      Serial.println(F("READY"));
      break;

    case 'R':
      estopAll();
      break;

    case 'Q':
      Serial.print(F("POS "));
      Serial.print(ax.pos / xpmm, 2);
      Serial.print(' ');
      Serial.println(ay.pos / ypmm, 2);
      break;

    case 'O':
      if (!idle) { replyErr(F("BUSY")); break; }
      ax.pos = 0;
      ay.pos = 0;
      estopped = false;
      replyOk();
      break;

    case 'Z': {
      if (!idle) { replyErr(F("BUSY")); break; }
      if (buf[1] == '0')      { zServo.write(SERVO_UP_DEG);   replyOk(); }
      else if (buf[1] == '1') { zServo.write(SERVO_DOWN_DEG); replyOk(); }
      else                    { replyErr(F("ARGS")); }
      break;
    }

    case 'F': {
      char *e;
      float f = strtod(buf + 1, &e);
      if (e == buf + 1) { replyErr(F("ARGS")); break; }
      if (f < FEED_MIN || f > FEED_MAX) { replyErr(F("RANGE")); break; }
      feedMmS = f;
      replyOk();
      break;
    }

    case 'C': {
      float nx, ny;
      if (!parse2f(buf + 1, nx, ny)) { replyErr(F("ARGS")); break; }
      if (nx < PMM_MIN || nx > PMM_MAX || ny < PMM_MIN || ny > PMM_MAX) {
        replyErr(F("RANGE"));
        break;
      }
      xpmm = nx;
      ypmm = ny;
      saveConfig();
      replyOk();
      break;
    }

    case 'J':
    case 'P': {
      if (estopped) { replyErr(F("ESTOP")); break; }   // 急停后须先 O 重新设原点
      if (!idle)    { replyErr(F("BUSY")); break; }
      float x, y;
      if (!parse2f(buf + 1, x, y)) { replyErr(F("ARGS")); break; }
      targetXmm = x;
      targetYmm = y;
      drilling = (c == 'P');
      beginMove(ax, x, xpmm);   // 零距离时立即 not-moving，状态机自然推进
      st = ST_MOVE_X;
      break;                    // 完成后统一回 DONE
    }

    default:
      replyErr(F("CMD"));
      break;
  }
}

// ---------------- 串口收行 ----------------
static char    lineBuf[LINE_BUF];
static uint8_t lineLen = 0;
static bool    lineOver = false;

static void serviceSerial() {
  while (Serial.available()) {
    char ch = (char)Serial.read();
    if (ch == '\n' || ch == '\r') {
      if (lineLen > 0 || lineOver) {
        if (lineOver) {
          replyErr(F("LONG"));
        } else {
          lineBuf[lineLen] = 0;
          handleLine(lineBuf);
        }
        lineLen = 0;
        lineOver = false;
      }
    } else if (lineLen < LINE_BUF - 1) {
      lineBuf[lineLen++] = ch;
    } else {
      lineOver = true;   // 超长：丢弃整行
    }
  }
}

// ============================================================
// Arduino 入口
// ============================================================
void setup() {
  // D2..D7 全部输出（PORTD 高 2 位是串口，不动）
  DDRD  |= 0xFC;
  // 全低：PUL/DIR = 0；ENA = 0（低有效 = 上电即锁相保持）
  PORTD &= 0x03;

  pinMode(X_LIM,     INPUT_PULLUP);
  pinMode(Y_LIM,     INPUT_PULLUP);
  pinMode(ESTOP_BTN, INPUT_PULLUP);

  zServo.attach(Z_SERVO);
  zServo.write(SERVO_UP_DEG);          // 上电默认抬钻

  loadConfig();

  Serial.begin(115200);
  delay(200);                          // 等 CH340 稳定再发开机横幅
  Serial.print(F(FW_NAME " " FW_VER " "));
  Serial.println(F("READY"));
}

void loop() {
  serviceSerial();   // 收命令（执行中收到非 R 命令回 ERR BUSY）
  checkEstopBtn();   // 预留硬件急停
  checkLimits();      // 预留限位保护
  runMachine();       // 脉冲发射 + 打孔状态机（非阻塞）
}

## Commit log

2026-09-13 初始提交：30音纸带音乐盒打孔程序（perfect-piano）
    双排键盘（上排和弦/下排主旋律）纸带打孔与播放程序，纯前端零依赖：MIDI 导入转换（白键化、栅格量化、换挡调度 400ms+提前量 600ms、最密间隔自动拉长纸带）；播放模拟（绿/红双扫描线 105mm 站间距同步、换挡过渡带、变速支持）；屏幕全方向 1:1 比例尺、适宽缩放、SVG/PNG 毫米级导出；附规格说明、自测页（123 项断言）、换挡测试 MIDI 与生成脚本。
2026-09-13 导入默认分配和弦 + 孔分色 + 幽灵孔修复
    - 导入对话框：音域均值最高轨默认主旋律(下排)，其余有音符轨默认和弦(上排)，补上 cho 选项缺失的 selected；单轨按音高拆分复选框默认勾选
    - 播放绘制孔按排分色：主旋律红橙 / 和弦绿，与双扫描线同色系；SVG/PNG 导出同步分色，换挡键孔保持描边
    - 修复幽灵孔：draw 循环 break 条件让出 105mm 站间距，避免 row1 孔漏画后在视口上部突现
    - app.js 版本号升至 v=19
2026-09-14 添加 MIDI 示例曲库
    梦中的婚礼、土耳其进行曲（3 个版本）共 4 首
2026-09-14 添加打孔机程序设计方案
    基于 打孔机.md 硬件规格：Nano+THB6128+NEMA17 三轴架构、
    脉冲当量标定、串口协议、网页端 Web Serial 上位机设计（待确认）
2026-09-14 打孔机固件 v1.0 + 设计方案定稿
    - 新增 puncher/firmware/puncher/puncher.ino：Arduino Nano 固件，
    THB6128×2 脉冲引擎（梯形加减速、端口直写）、PWM 舵机打孔状态机
    （45°下压2s/90°抬起）、ASCII 行协议（V/O/J/P/Z/F/C/Q/R）、
    EEPROM 校准存储、急停与预留限位；Nano 编译通过（Flash 29%/RAM 17%）
    - 设计方案定稿：4 个待确认问题落定（Z 轴为 PWM 舵机），
    打孔排序修正为 x 主序 y 次序，协议补充 Q 查询与应答语义
    [puncher.ino]
2026-09-14 打孔机上位机面板 + Web Serial + 协议测试
    - 新增 js/punch-sender.js：任务生成（x 主序 y 次序、拉长曲换算）、
    .punch 导出、用时估算、Web Serial 串口链路（连接/握手/行分派）、
    打孔面板（点动对刀/设原点/进给/校准/试打/逐孔 ACK 流控/暂停/急停）
    - index.html 增加打孔机工具栏按钮与控制对话框
    - test.html 新增 14 项打孔：断言，总计 137/137 通过（浏览器实测）
    - 修正 Y 轴理论当量 388.02 → 388.03（25600/π/21 精确值，同步
    固件注释/设计方案/界面默认值）
    [puncher.ino]
2026-09-14 添加项目 README
2026-09-14 README 更名：纸带钢琴工坊，去除品牌字样
2026-09-14 文件与代码去品牌化：完美钢琴字样 → 纸带钢琴
    - 重命名：纸带钢琴.txt / 纸带钢琴.jpg / 纸带打孔图.png / 纸带打孔图.svg
    （旧 纸带打孔图.png 为初始提交中的早期导出稿，已被新图覆盖，
    历史版本仍可从 a4314e2 找回）
    - 页面标题/品牌栏改为「纸带钢琴工坊」，导出文件名同步去品牌化
    - 固件与脚本头注释同步更新
2026-09-14 换挡排产：修复首音超窗场景的纸带头边界与硬时间约束
    排查土耳其进行曲首音是否在 C4~B5 窗口内时发现：
    - 伴奏轨（E2~F#4）首音低于 C4，须在纸带头部留白内先打降挡孔——逻辑已有
    - minShiftCol 用 floor 存在 off-by-one：-5.78 取整到 -6 会打到带头 1.5mm
    处（孔缘距边仅 0.3mm，易破），改 ceil 后 -5 → y=3.75mm 边距充足
    - pressColFor 触底时不再无条件接受：须满足 400ms 换挡硬耗时（键盘
    到位），否则返回 null 钳制（物理无解）；600ms 满余量放不下但能
    到位的极限快曲仍可换挡
    自测 148/148 通过（新增 7d 组 11 项：首音超窗降挡、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
2026-09-16 档位模型改造 + 曲首强制归位 + 导出几何修复
    - 档位表 GEAR_STARTS(A0/A2/A4/D6) 四档 14 白键窗口，scheduleRow 按窗口映射轨道
    - 曲首归位：连按 3 次 ◀ 钉底 A0，homeOk=false 时整曲顺延重试（导入对话框 chkHome 默认开启）
    - 调号分段自动移调：midi-parser 解析 keysigs，按段独立选调（土耳其进行曲 0/+3/0/-4）
    - 修复 exportGeometry hMM 漏传拉长倍率：拉长曲 SVG/PNG 导出不再裁掉底部孔
    - 音名栏/到界提示按档位渲染，工程 JSON 兼容负列归位孔
    - test.html 新增归位专项与回归用例，194/194 全绿
2026-09-16 西部世界纸带导出图（完整 3.09m + 头部 400mm 特写）
2026-09-16 换挡孔分色导出：SVG/PNG 按 ◀◀ 红 / ▶▶ 绿 描边（与屏幕渲染一致）
    - exportSVG / exportPNG 换挡孔从灰描边改为按方向分色（lane0 #c9563a / lane15 #4d9a6c）
    - app.js v23；重新导出西部世界纸带图（含分色换挡孔）
2026-09-16 换挡孔屏幕渲染改空心：纸带底色填充 + 彩色描边（与导出一致，v24）
2026-09-16 N=8 新机械模型重写转换与播放（v13/v26）：每键一滚轮 13 键/档、档位 A0..A5/D6、音高原样落轨移除自动移调；新增规格文档替换旧 txt
2026-09-17 N=7 虚拟黑键槽位模型（v14/v27）：均匀槽栅 133mm 档位宽、8 档 A0..D6、D=5.09mm、换挡孔 y 错开 5mm + 孔距守卫；test 162/162 全绿
2026-09-17 档位宽度 133→130mm（v15）：换挡轮距边 4.4mm 使角落孔对纯 x 达标 2mm 全规格，取消换挡孔 y 错开；D=4.97mm；test 162/162 全绿
2026-09-17 改为 N=8 虚拟黑键槽位模型，上止点提至 C7
    键盘简化为白黑严格交替的均匀槽栅（E-F、B-C 处插虚拟黑键占位），每档 15 槽 = 13 真实键 + 2 虚拟位（每排 17 滚轮），档位步进 14 槽恰为一个八度，档位表 A0→A6 后补 C7 上止点，八档合起来覆盖钢琴全音域 A0..C8。档位宽 130mm 定出白键 9.286 / 黑键 7.959 / 槽栅距 8.622，两排错开 D=p/2≈4.311；孔缘 1.5mm 规格（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
2026-09-17 新增跨排救援：钳制音移到恰在该档的另一排击发
    本排换挡来不及被钳制的音，若另一排在同一拍恰好已停在含该音的档位（无需为其新增换挡），移到另一排击发并移除本排钳制孔。两排键盘同构同音色、同拍孔本就同时触发，救援零时序损失、不改另一排换挡轨迹。梦中的婚礼实测：钳制 161→152，9 音移排。test.html 新增 6 项断言，180/180 全绿。
2026-09-18 实现混合换挡：整档键 ±1 八度 + 半音键 ±1 半音双轨交替
    键盘位置改为连续锚槽 s∈[0,88]：整档键 ±14 槽/按（400ms），半音键 ±1 槽/按（10ms 瞬时，a/b 双轨交替，步进 2.25mm、同轨 ≥4.5mm）。每排 17→21 滚轮（全上统一槽栅，跨排最小孔心距仍 D≈4.31），纸带 150→200mm（两侧边距 ~10.4mm）。目标锚槽取按压数最少（含过冲回调，如 +13 = 整档+14−半音1）；同拍音符组感知目标锚槽，同拍和弦不再钳制；归位改 7 按钉底（修复原 3 按在 W_MAX=7 下到不了底的 bug）；修复时间线早退 bug（整档滑行中夹瞬时半音事件时位置算错）。梦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
2026-09-18 按定案规格回退为单换挡：N=8 / 纸带 150mm / 档位宽 130mm / 孔缘 1.5mm
    移除混合换挡（21 轨、半音键、纸带 200mm），恢复单换挡 + 跨排救援模型，并保留两处修复：曲首归位连按 3 改 7 次（W_MAX=7 时 3 次到不了底，HOME_PRESSES = ⌈88/14⌉）；相关注释与 UI 文案同步。梦中的婚礼实测：2054 孔、换挡 119/291、钳制 152 + 救援 9、归位 ◀×7/7、顺延 12 拍。test.html 182 项断言全绿。
2026-09-18 新增纸带驱动滚轮 SolidWorks 模型与三视图
    滚轮：Ø40×2mm 圆盘 + 边缘均布 4 个矩形凸起（径向高 3mm 至 Ø46，周向宽 4mm），体积 2610.34mm³ 验证通过。含零件 SLDPRT、GB A3 三视图工程图（SLDDRW + PDF）、模型预览 PNG，以及自动化建模/验证/出图脚本（pywin32 早绑定，本机 SW 2026 GetTypeInfo 损坏需 makepy 手动包装）。
    [roller_d40x2_4bumps.SLDPRT, roller_d40x2_4bumps_views.SLDDRW]
2026-09-18 移除误提交的 SolidWorks 锁文件并忽略 ~\$*
2026-09-18 移除 SolidWorks 锁文件
2026-09-18 滚轮 v2：PVC 激光切割版（厚 1.5mm + Ø15 中心孔 + 齿顶 R2 半圆头）
    模型改为 1.5mm 厚 PVC 板，中心孔 Ø15（与盘环同草图套挖），齿顶两角 R2（4mm 齿宽 + 2×R2 = 半圆头防割纸），SW 材质设为 PVC；体积 1682.38mm³ 与解析值偏差 0.00%。新增激光切割 DXF（解析几何 1:1，17 实体）与 SVG 预览，回读校验轮廓闭合、齿顶外凸 R23、孔 R7.5；三视图工程图（GB A3）同步更新。旧版 Ø40×2 模型保留。
    [roller_d40x1p5_h15.SLDPRT, roller_d40x1p5_h15_views.SLDDRW, roller_laser_pvc1p5.dxf]
2026-09-18 突台取消圆角，高度按相邻顶点连线切于滚轮重算为 8.28mm
    突台改平顶矩形（宽 4mm），顶点半径 h = R/cos45° = R√2 = 28.2843mm，突出高度 h−R = 8.2843mm——相邻两突台顶点间纸带直线段恰好切于 R20 滚轮面的临界高度（再矮切进实体、再高出间隙）。厚 1.5mm / Ø15 中心孔 / PVC 不变。模型体积 1819.51 vs 解析 1819.56（0.00%），DXF 回读校验轮廓闭合、弧在 R20 上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
    [roller_d40x1p5_h15.SLDPRT, roller_d40x1p5_h15_views.SLDDRW, roller_laser_pvc1p5.dxf]
2026-09-18 工程图自动导入模型尺寸：前视 Ø40/Ø15/齿顶圆Ø56.57/齿宽4，上视厚度1.5
    - 修复齿顶圆尺寸错挂（矩形线段顺序不可靠，改按端点半径几何识别齿顶边，38→56.57）；InsertModelAnnotations3 在 IDrawingDoc 上，Types=32768(MarkedForDrawing)，8/1 均无效；预打开零件并激活视图；去重后修剪为前视4尺+上视1厚度；CloseAllDocuments(True) 修复脏文档占用致 SLDDRW 静默保存失败
    [roller_d40x1p5_h15.SLDPRT, roller_d40x1p5_h15_views.SLDDRW]
2026-10-08 midi: add Fur Elise (bitmidi 48169, 2-track piano, full piano range)
